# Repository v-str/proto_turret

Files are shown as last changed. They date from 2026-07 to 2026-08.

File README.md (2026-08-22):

<div align="center">

# proto_turret

**Панорамно-наклонная турель на STM32F446RE под управлением ROS 2 (micro-ROS)**







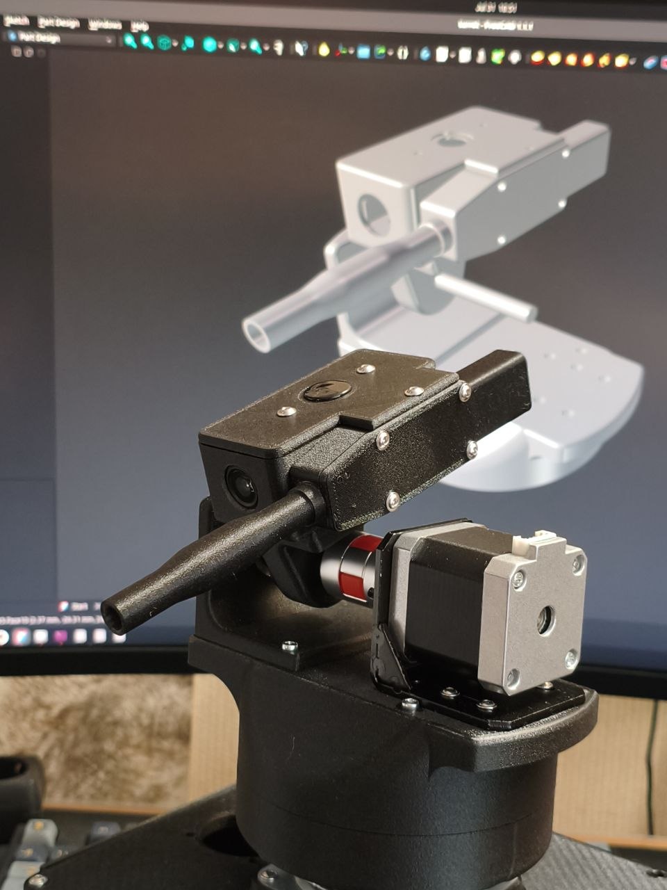
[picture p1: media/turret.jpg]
Собранная турель proto_turret


</div>

---

## О проекте

**proto_turret** — двухосевая турель (панорама + наклон), которая управляется через ROS 2.
Прошивка STM32 построена на **FreeRTOS** и **micro-ROS**: плата становится полноценной нодой
ROS-сети, обмениваясь сообщениями с ПК через UART (DMA + IDLE-прерывание).

На хосте работает Qt6-приложение: получает видео с USB-камеры, рисует прицельный интерфейс,
а движение мыши превращает в команды положения для турели.

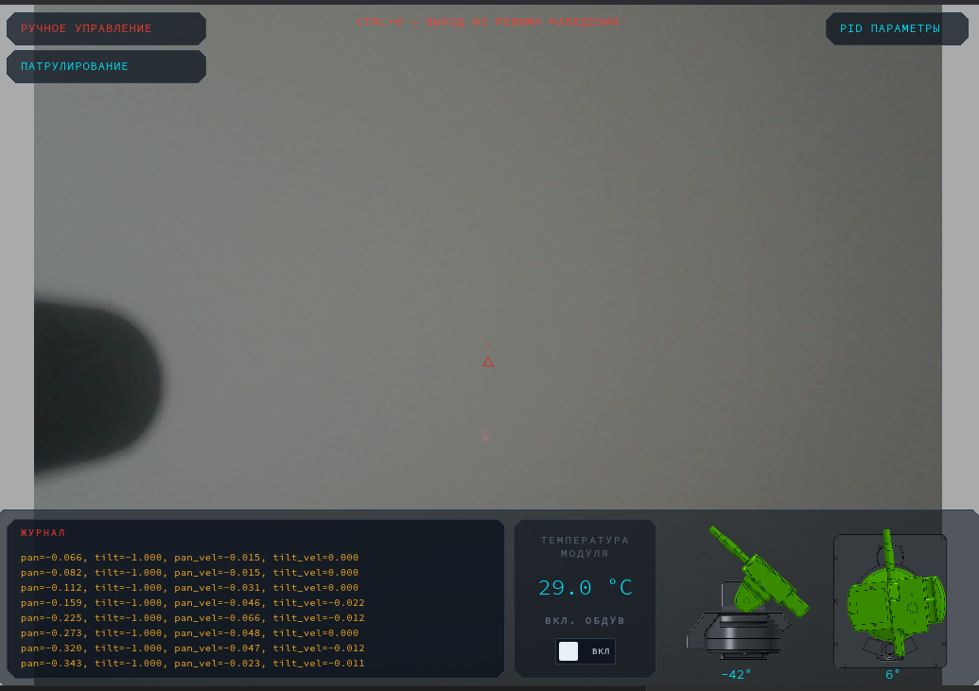
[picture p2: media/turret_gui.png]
Qt6 GUI турели


## Возможности

- 2 оси (pan/tilt) на шаговых двигателях NEMA17 с драйверами TMC2209 (STEP/DIR)
- Замкнутая обратная связь: магнитные энкодеры **AS5600** по каждой оси (I2C)
- **Автокалибровка** обеих осей по концевикам одним вызовом ROS-сервиса
- **PID-регуляция** скорости с раздельными коэффициентами на каждую ось,
  настройка всех 14 параметров **в рантайме** через ROS-сервис
- Телеметрия: углы осей, состояние 4 концевиков, температура (**LM75**, I2C)
- Управление охлаждающим вентилятором прямо из команды движения
- Аппаратная защита: моторы отключены до подключения агента; стоп при отсутствии
  команд дольше 100 мс; таймаут калибровки по числу шагов
- Корпус напечатан на 3D-принтере (FreeCAD-модели и STL приложены)

**Как это работает при загрузке:**

1. Плата стартует с **выключенными** драйверами моторов (EN = HIGH).
2. Главный цикл пингует micro-ros-agent каждые 2 секунды.
3. Когда агент найден → создаётся нода `proto_turret_node`: подписчик команд, публикация
   телеметрии, сервисы калибровки и PID-параметров.
4. Второй поток (`Ros2TaskExecutor`) разбирает очередь команд и управляет турелью.
   Если команды перестали приходить более чем на 100 мс — моторы останавливаются.
5. По запросу сервиса `/turret_calibrate` турель едет до концевиков каждой оси,
   считает шаги полного хода и принимает середину за ноль градусов.

## Железо

| Компонент | Модель | Подключение |
|---|---|---|
| Плата | NUCLEO-F446RE (STM32F446RE, Cortex-M4 @ 180 МГц) | USB (ST-Link + VCP) |
| Моторы | 2× NEMA17 | STEP/DIR (TIM10/TIM11) |
| Драйверы | 2× TMC2209 | STEP/DIR + EN (GPIO) |
| Энкодеры | 2× AS5600 | I2C1 (400 кГц) / I2C2 (100 кГц) |
| Датчик температуры | LM75 | I2C3 (100 кГц) |
| Концевики | 4 шт (лево/право, перед/зад) | GPIO |
| Вентилятор | — | GPIO |
| Камера | любая USB | хост-ПК |
| Канал связи | UART2, 115200 бод, DMA circular 2048 Б + IDLE | micro-ROS |

## Прошивка

Исходники — в [`Core/Src`](Core/Src). Проект генерируется CubeMX ([`proto_turret.ioc`](proto_turret.ioc)),
сборка через Makefile (arm-none-eabi-gcc, hard-float).

| Модуль | Назначение |
|---|---|
| [`transport.c`](Core/Src/transport.c) | весь micro-ROS: инициализация ноды, подписчик, публикаторы, сервисы, ping агента |
| [`turret_tasks.c`](Core/Src/turret_tasks.c) | потоки FreeRTOS, очередь команд, автокалибровка осей |
| [`motor_control.c`](Core/Src/motor_control.c) | STEP/DIR управление TMC2209, PID, движение до концевика |
| [`pid_struct.c`](Core/Src/pid_struct.c) | шаг PID-регулятора (сглаживание скорости, лимит разгона) |
| [`sensors.c`](Core/Src/sensors.c) | чтение AS5600 и LM75, медианный фильтр, восстановление зависшей I2C-шины |
| [`constants.h`](Core/Inc/constants.h) | все настраиваемые константы прошивки в одном файле |

Все настройки ROS-имён, PID, таймингов — в [`constants.h`](Core/Inc/constants.h).

### Потоки FreeRTOS

| Поток | Что делает |
|---|---|
| `defaultTask` (`StartDefaultTask`) | пинг агента → init micro-ROS → цикл `spin_some` + публикация телеметрии |
| `ros2TaskExecutor` | ждёт команду из очереди (таймаут 100 мс), двигает моторы по PID, включает вентилятор |

## ROS-интерфейс

Нода: **`/proto_turret_node`**

Кастомные сообщения и сервисы живут в пакете
[`microros_component/extra_packages/proto_turret_interfaces`](microros_component/extra_packages/proto_turret_interfaces)
и подхватываются при сборке libmicroros.

### Топики

| Направление | Имя | Тип | Частота |
|---|---|---|---|
| подписка | `/proto_turret_cmd` | `proto_turret_interfaces/msg/TurretCommand` | по мере прихода |
| публикация | `/proto_turret_stm32_publisher` | `proto_turret_interfaces/msg/TurretStatus` | 4 Гц |
| публикация | `/proto_turret_as5600` | `std_msgs/msg/Int32MultiArray` | 10 Гц |

```text
# TurretCommand.msg — команда от GUI
float32 pan_pos       # цель по панораме
float32 tilt_pos      # цель по наклону
float32 pan_vel
float32 tilt_vel
bool fan_enable       # включить вентилятор
```

```text
# TurretStatus.msg — телеметрия платы
uint8 switch_mask     # биты 0..3: левый, правый, передний, задний концевики
float32 temperature   # LM75, °C
bool fan_enable
int32 pan_angle       # текущий угол панорамы
int32 tilt_angle      # текущий угол наклона
```

`Int32MultiArray` на `/proto_turret_as5600` — сырые отсчёты энкодеров `[M1, M2, ошибки]`
(0..4095, `-1` = нет ответа) для отладки.

### Сервисы

| Имя | Тип | Назначение |
|---|---|---|
| `/turret_calibrate` | `proto_turret_interfaces/srv/TurretCalibrate` | автокалибровка обеих осей по концевикам, ответ `success` |
| `/turret_pid_params` | `proto_turret_interfaces/srv/PidParams` | применение 14 PID-коэффициентов (kp/ki/kd/smooth/rate/corr_max/speed_max × 2 оси) без перепрошивки |

## Сборка и запуск

### Что понадобится

- **Docker** — для сборки `libmicroros.a`
- **arm-none-eabi-gcc** + make — для сборки прошивки (либо всё то же в Docker)
- **OpenOCD** + ST-Link — для прошивки
- **ROS 2** на хосте и собранный из исходников `micro_ros_agent`
- ROS 2: библиотека micro-ROS собрана под Humble, хост-стек — Lyrical

### Сборка прошивки

```bash
git clone https://github.com/v-str/proto_turret.git
cd proto_turret

# 1. libmicroros.a в Docker (образ microros/micro_ros_static_library_builder:humble-cached;
#    внутри контейнера также собираются интерфейсы из microros_component/extra_packages)
./build_lib_docker.sh

# 2. Прошивка
make -j$(nproc)            # результат: build/proto_turret.hex/.bin/.elf
# либо полностью в Docker: ./build_fw_docker.sh

# 3. Прошивка платы через ST-Link (program + verify + reset)
./flash_stm32.sh
```

### Запуск на хосте

```bash
# 4. micro-ros-agent (нативно, не в Docker — так надёжнее для DDS)
./agent_start_native.sh

# 5. В другом терминале
source /opt/ros/lyrical/setup.bash
ros2 node list                          # → /proto_turret_node
ros2 topic echo /proto_turret_stm32_publisher

# 6. Откалибровать обе оси (поедет до концевиков и вернётся в центр)
ros2 service call /turret_calibrate proto_turret_interfaces/srv/TurretCalibrate "{}"

# 7. Подёрнуть турель вручную
ros2 topic pub --once /proto_turret_cmd proto_turret_interfaces/msg/TurretCommand \
  "{pan_pos: 0.3, tilt_pos: 0.0, pan_vel: 0.0, tilt_vel: 0.0, fan_enable: false}"
```

## Механика

Корпус и узлы турели спроектированы в FreeCAD — исходники в [`freecad/`](freecad),
готовые к печати STL (43 детали) — в [`freecad/stl/`](freecad/stl):

- `turret.FCStd` — основной корпус: колпак, дверца, ствол, капоты моторов, Y-сочленение
- `bottom_rails.FCStd` — нижние направляющие и углы
- `as5600_plate.FCStd` — крепление энкодеров AS5600
- `raspr_plata_holder.FCStd` — держатель распределительной платы

## Структура репозитория

```text
proto_turret/
├── Core/                        # исходники прошивки (main, задачи, транспорт, моторы, датчики)
├── Drivers/, Middlewares/       # HAL STM32 + CMSIS, FreeRTOS
├── micro_ros_stm32cubemx_utils/ # интеграция micro-ROS в CubeMX-проект (libmicroros.a)
├── microros_component/
│   └── extra_packages/
│       └── proto_turret_interfaces/   # кастомные msg/srv ROS
├── freecad/                     # 3D-модели (FreeCAD) и STL для печати
├── media/                       # фото и скриншоты
├── proto_turret.ioc             # проект CubeMX
├── Makefile                     # сборка прошивки (arm-none-eabi-gcc)
├── build_lib_docker.sh          # сборка libmicroros.a в Docker
├── build_fw_docker.sh           # сборка прошивки в Docker
├── flash_stm32.sh               # прошивка через OpenOCD + ST-Link
└── agent_start_native.sh        # запуск micro-ros-agent на хосте
```

## Статус

- [x] Транспорт micro-ROS: UART2 DMA + IDLE, автоматическое переподключение к агенту
- [x] Управление двумя осями STEP/DIR
- [x] Автокалибровка по концевикам
- [x] Энкодеры AS5600 с фильтрацией скачков
- [x] PID-регуляция + runtime-настройка через ROS-сервис
- [x] Телеметрия: концевики, температура LM75, углы осей
- [x] Qt6 GUI на хосте: видео, прицеливание мышью, PID-панель

---

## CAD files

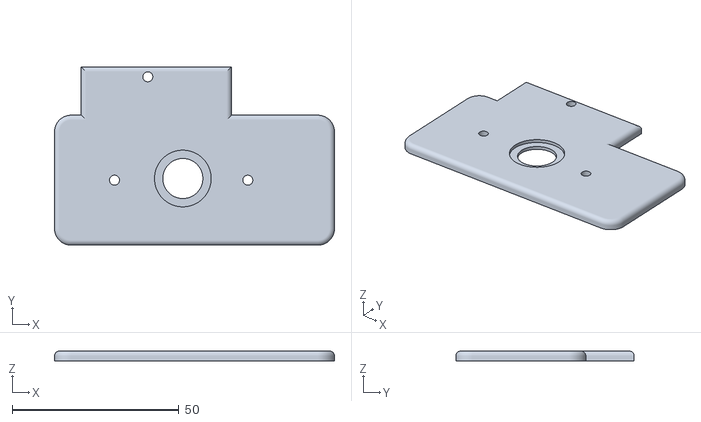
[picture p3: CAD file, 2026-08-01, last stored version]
freecad/stl/turret-turret_main_cap.stl
84.0 x 53.5 x 3.00

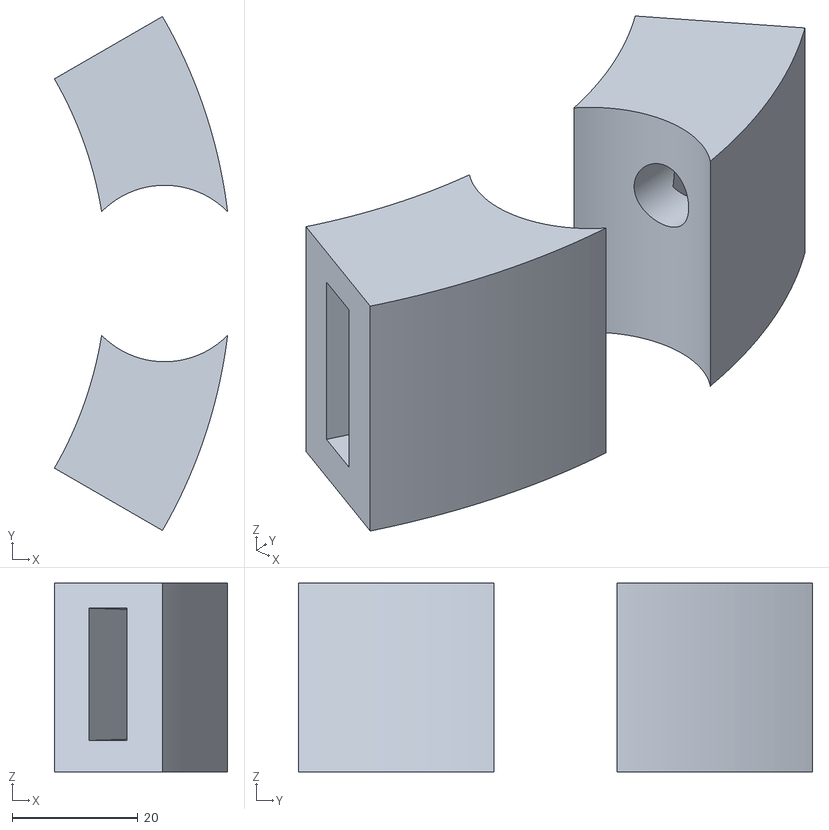
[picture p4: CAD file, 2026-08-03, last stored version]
freecad/stl/turret-head_konceviki_arms.stl
27.5 x 81.6 x 30.0

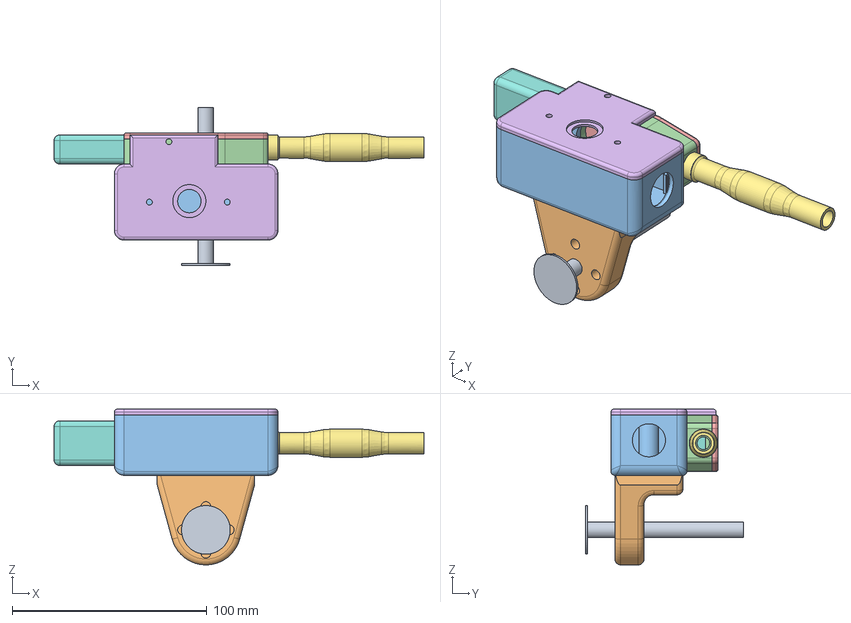
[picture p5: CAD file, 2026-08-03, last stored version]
freecad/turret.FCStd
190.0 x 81.0 x 80.0 mm
temp1
val_joint_y
turret_camera
turret_gun_base
turret_gun_base_cap
turret_main_cap
the_gun
the_gun_back

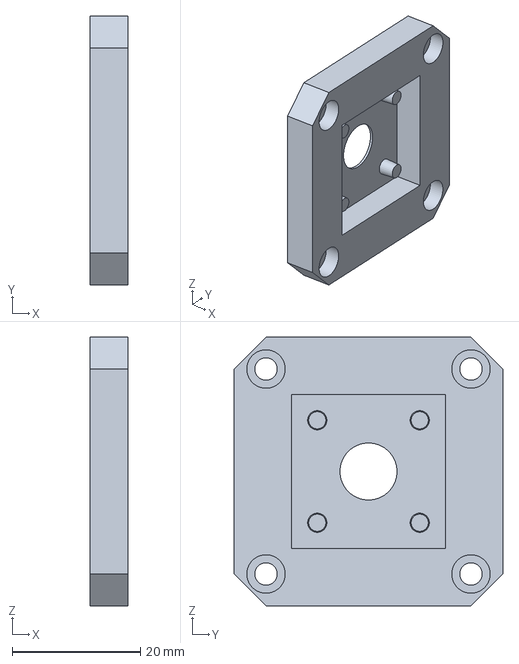
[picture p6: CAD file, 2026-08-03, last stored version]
freecad/as5600_plate.FCStd
6.00 x 42.0 x 42.0 mm

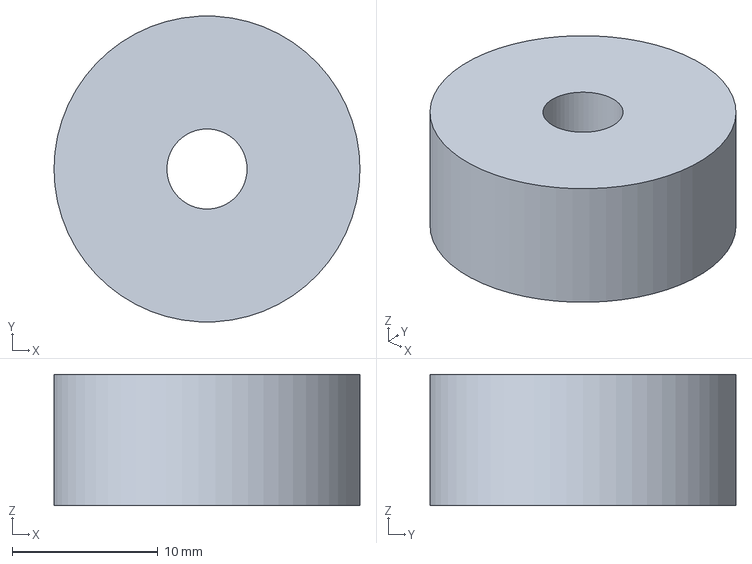
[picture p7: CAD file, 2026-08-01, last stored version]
freecad/motor_pan_gasket.FCStd
21.0 x 21.0 x 9.00 mm

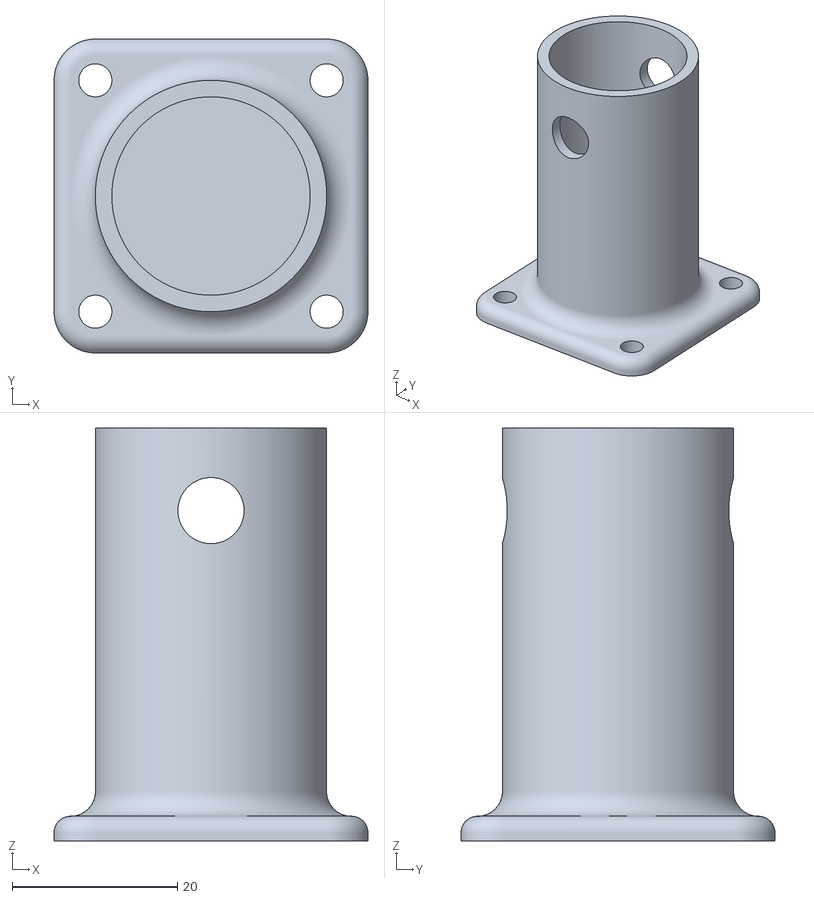
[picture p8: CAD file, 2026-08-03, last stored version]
freecad/stl/turret-head_konceviki_plate.stl
38.0 x 38.0 x 50.0

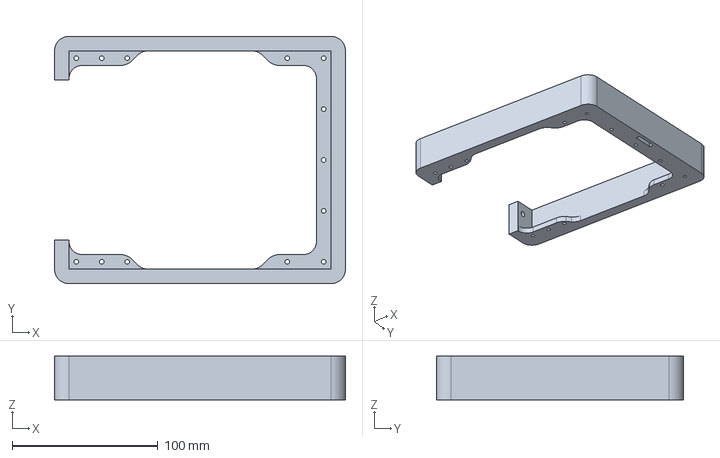
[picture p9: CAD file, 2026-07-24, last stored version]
freecad/box.FCStd
200.0 x 170.0 x 30.0 mm

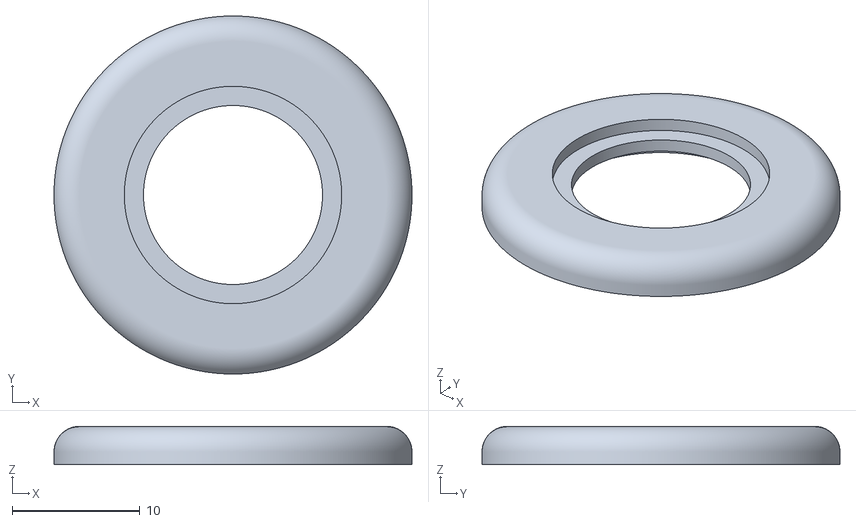
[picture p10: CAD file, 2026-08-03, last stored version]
freecad/stl/turret-head_konceviki_cap.stl
28.0 x 28.0 x 3.00

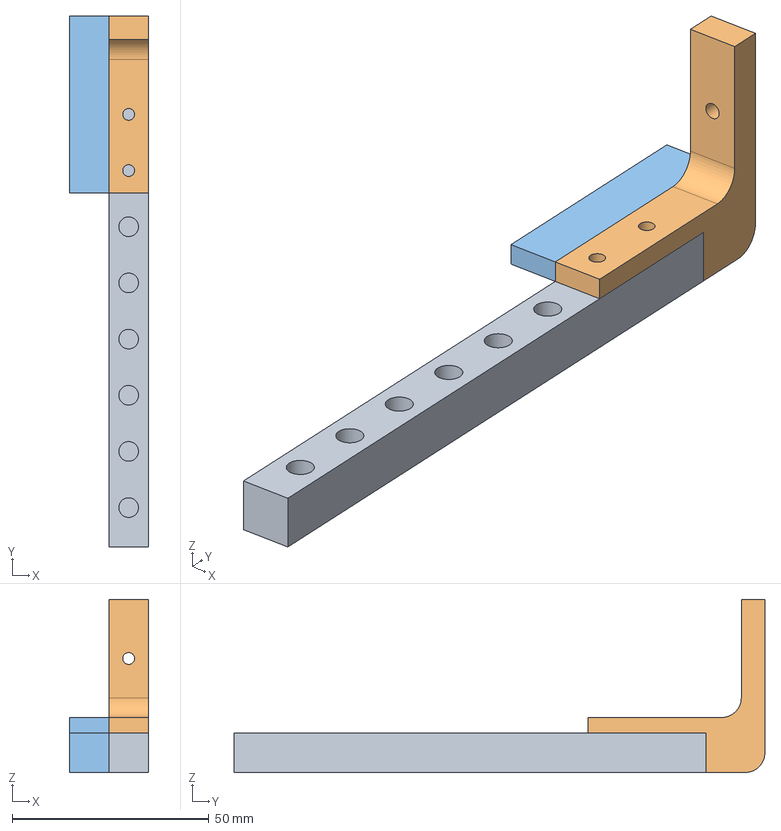
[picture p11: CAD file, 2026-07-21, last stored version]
freecad/bottom_rails.FCStd
20.0 x 135.0 x 44.0 mm
bottom_rails
corners
corner_side

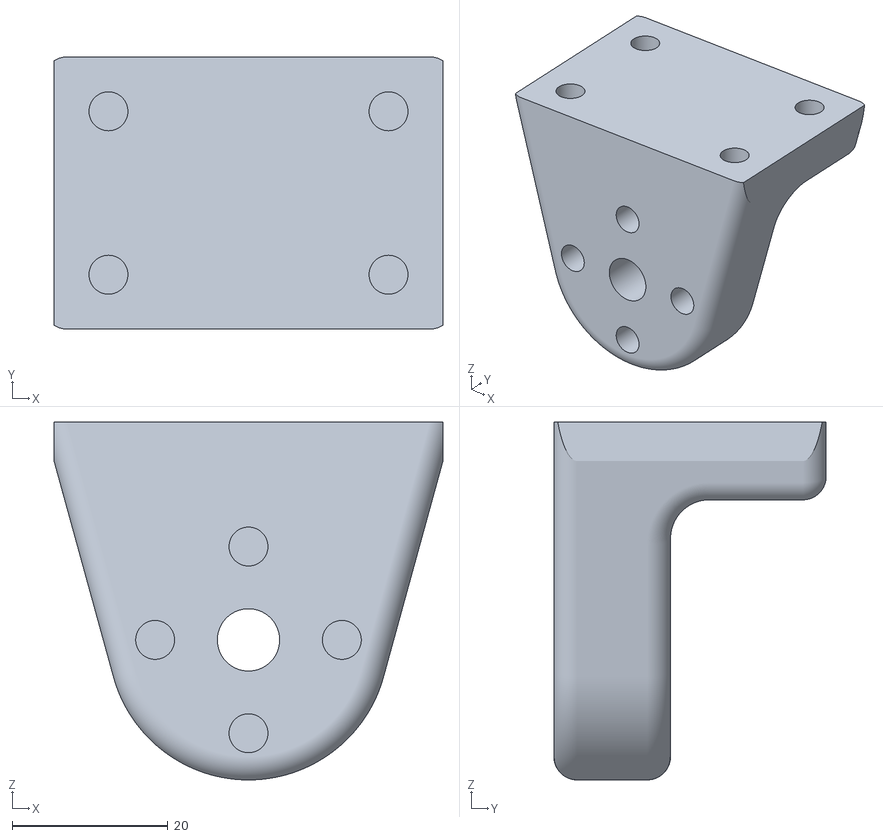
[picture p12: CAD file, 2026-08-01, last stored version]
freecad/stl/turret-val_joint_y.stl
50.0 x 35.0 x 46.0

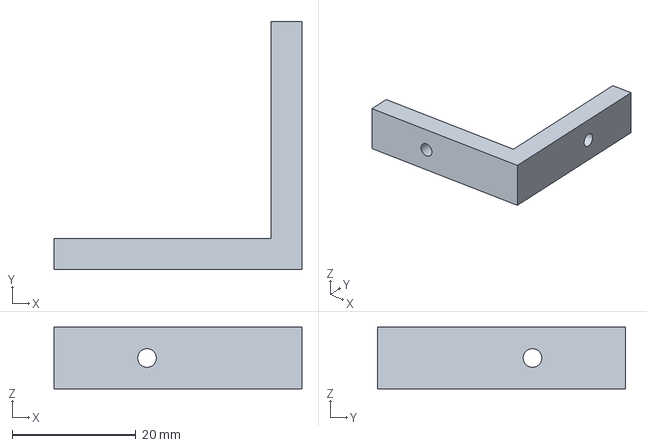
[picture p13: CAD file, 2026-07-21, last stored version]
freecad/corners_small_plate.FCStd
40.0 x 40.0 x 10.0 mm

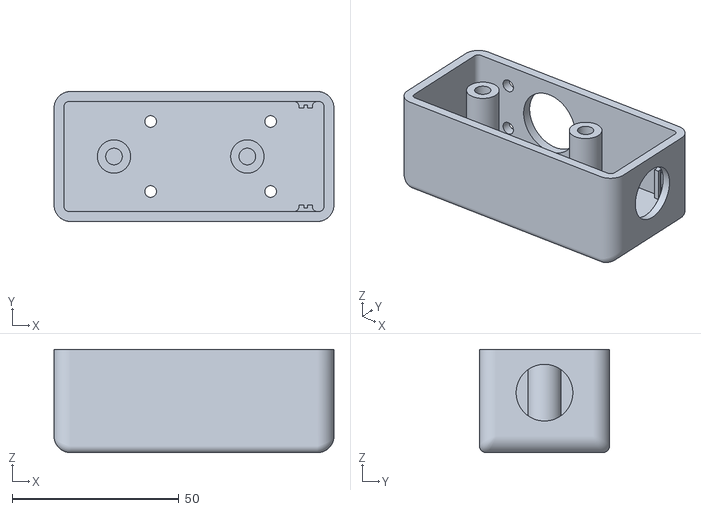
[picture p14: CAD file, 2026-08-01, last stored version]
freecad/stl/turret-turret_camera.stl
84.0 x 39.0 x 31.0

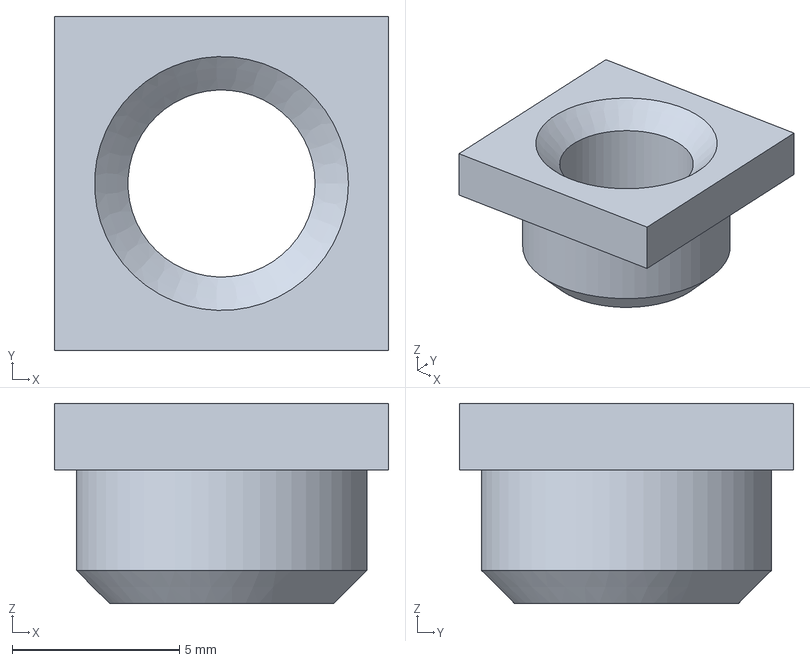
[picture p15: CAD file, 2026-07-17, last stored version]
freecad/magnet_template_helper.FCStd
10.0 x 10.0 x 6.00 mm

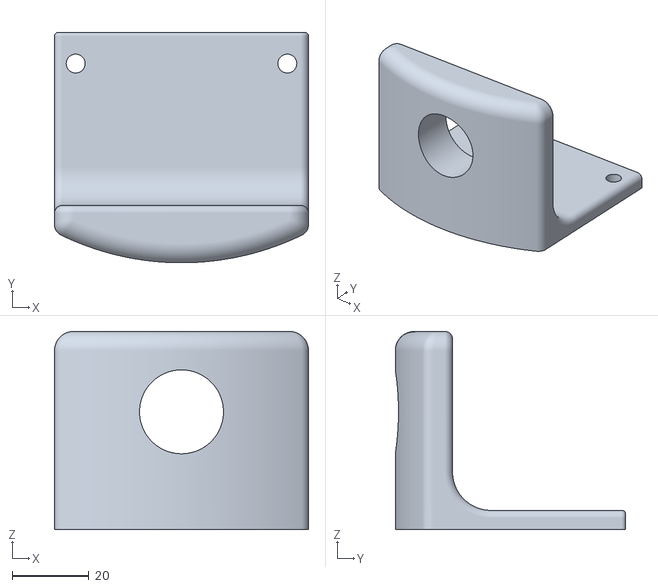
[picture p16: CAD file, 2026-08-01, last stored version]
freecad/stl/turret-motor_y_joint.stl
66.0 x 59.9 x 51.5

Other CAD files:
freecad/stl/as5600_plate-as5600_plate.stl
freecad/stl/motor_pan_gasket-motor_gasket.stl
freecad/stl/turret-the_gun.stl
freecad/stl/turret-gun_konceviki.stl
freecad/stl/bottom_rails-Body.stl
freecad/stl/bottom_rails-corner_side.stl
freecad/stl/box-Inter_stick.stl
freecad/stl/box-bottom_plate.stl
freecad/stl/box-great_wall.stl
freecad/stl/box-supply_unit_holder.stl
freecad/stl/box-wall_1.stl
freecad/stl/box-wall_2.stl
freecad/stl/box-wall_3.stl
freecad/stl/corners_small_plate-Body.stl
freecad/stl/magnet_template_helper-Body.stl
freecad/stl/rails-corners.stl
freecad/stl/turret-box_cap_gasket.stl
freecad/stl/turret-cap.stl
freecad/stl/turret-door.stl
freecad/stl/turret-head_motor_plate.stl
freecad/stl/turret-motor_hood_box.stl
freecad/stl/turret-motor_hood_roof.stl
freecad/stl/turret-motor_tilt_plate.stl
freecad/stl/turret-plate_joints.stl
freecad/stl/turret-the_gun_back.stl
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

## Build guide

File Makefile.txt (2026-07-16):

##########################################################################################################################
# File automatically-generated by tool: [projectgenerator] version: [4.10.0-B28] date: [Thu Jul 16 12:32:29 MSK 2026] 
##########################################################################################################################

# ------------------------------------------------
# Generic Makefile (based on gcc)
#
# ChangeLog :
#	2017-02-10 - Several enhancements + project update mode
#   2015-07-22 - first version
# ------------------------------------------------

######################################
# target
######################################
TARGET = proto_turret

######################################
# building variables
######################################
# debug build?
DEBUG = 1
# optimization
OPT = -Og

#######################################
# paths
#######################################
# Build path
BUILD_DIR = build

######################################
# source
######################################
# C sources
C_SOURCES =  \
Core/Src/main.c \
Core/Src/freertos.c \
Core/Src/stm32f4xx_it.c \
Core/Src/stm32f4xx_hal_msp.c \
Core/Src/stm32f4xx_hal_timebase_tim.c \
Drivers/BSP/STM32F4xx-Nucleo/stm32f4xx_nucleo.c \
Drivers/STM32F4xx_HAL_Driver/Src/stm32f4xx_hal_tim.c \
Drivers/STM32F4xx_HAL_Driver/Src/stm32f4xx_hal_tim_ex.c \
Drivers/STM32F4xx_HAL_Driver/Src/stm32f4xx_hal_rcc.c \
Drivers/STM32F4xx_HAL_Driver/Src/stm32f4xx_hal_rcc_ex.c \
Drivers/STM32F4xx_HAL_Driver/Src/stm32f4xx_hal_flash.c \
Drivers/STM32F4xx_HAL_Driver/Src/stm32f4xx_hal_flash_ex.c \
Drivers/STM32F4xx_HAL_Driver/Src/stm32f4xx_hal_flash_ramfunc.c \
Drivers/STM32F4xx_HAL_Driver/Src/stm32f4xx_hal_gpio.c \
Drivers/STM32F4xx_HAL_Driver/Src/stm32f4xx_hal_dma_ex.c \
Drivers/STM32F4xx_HAL_Driver/Src/stm32f4xx_hal_dma.c \
Drivers/STM32F4xx_HAL_Driver/Src/stm32f4xx_hal_pwr.c \
Drivers/STM32F4xx_HAL_Driver/Src/stm32f4xx_hal_pwr_ex.c \
Drivers/STM32F4xx_HAL_Driver/Src/stm32f4xx_hal_cortex.c \
Drivers/STM32F4xx_HAL_Driver/Src/stm32f4xx_hal.c \
Drivers/STM32F4xx_HAL_Driver/Src/stm32f4xx_hal_exti.c \
Drivers/STM32F4xx_HAL_Driver/Src/stm32f4xx_hal_uart.c \
Core/Src/system_stm32f4xx.c \
Middlewares/Third_Party/FreeRTOS/Source/croutine.c \
Middlewares/Third_Party/FreeRTOS/Source/event_groups.c \
Middlewares/Third_Party/FreeRTOS/Source/list.c \
Middlewares/Third_Party/FreeRTOS/Source/queue.c \
Middlewares/Third_Party/FreeRTOS/Source/stream_buffer.c \
Middlewares/Third_Party/FreeRTOS/Source/tasks.c \
Middlewares/Third_Party/FreeRTOS/Source/timers.c \
Middlewares/Third_Party/FreeRTOS/Source/CMSIS_RTOS_V2/cmsis_os2.c \
Middlewares/Third_Party/FreeRTOS/Source/portable/MemMang/heap_4.c \
Middlewares/Third_Party/FreeRTOS/Source/portable/GCC/ARM_CM4F/port.c \
Core/Src/sysmem.c \
Core/Src/syscalls.c \
micro_ros_stm32cubemx_utils/extra_sources/microros_transports/dma_transport.c \
micro_ros_stm32cubemx_utils/extra_sources/microros_allocators.c \
micro_ros_stm32cubemx_utils/extra_sources/custom_memory_manager.c \
micro_ros_stm32cubemx_utils/extra_sources/microros_time.c

# ASM sources
ASM_SOURCES =  \
startup_stm32f446xx.s

# ASMM sources
ASMM_SOURCES = 

#######################################
# binaries
#######################################
PREFIX = arm-none-eabi-
# The gcc compiler bin path can be either defined in make command via GCC_PATH variable (> make GCC_PATH=xxx)
# either it can be added to the PATH environment variable.
ifdef GCC_PATH
CC = $(GCC_PATH)/$(PREFIX)gcc
AS = $(GCC_PATH)/$(PREFIX)gcc -x assembler-with-cpp
CP = $(GCC_PATH)/$(PREFIX)objcopy
SZ = $(GCC_PATH)/$(PREFIX)size
else
CC = $(PREFIX)gcc
AS = $(PREFIX)gcc -x assembler-with-cpp
CP = $(PREFIX)objcopy
SZ = $(PREFIX)size
endif
HEX = $(CP) -O ihex
BIN = $(CP) -O binary -S
 
#######################################
# CFLAGS
#######################################
# cpu
CPU = -mcpu=cortex-m4

# fpu
FPU = -mfpu=fpv4-sp-d16

# float-abi
FLOAT-ABI = -mfloat-abi=hard

# mcu
MCU = $(CPU) -mthumb $(FPU) $(FLOAT-ABI)

# macros for gcc
# AS defines
AS_DEFS = 

# C defines
C_DEFS =  \
-DUSE_NUCLEO_64 \
-DUSE_HAL_DRIVER \
-DSTM32F446xx

# AS includes
AS_INCLUDES =  \
-ICore/Inc \
-IDrivers/STM32F4xx_HAL_Driver/Inc \
-IDrivers/STM32F4xx_HAL_Driver/Inc/Legacy \
-IMiddlewares/Third_Party/FreeRTOS/Source/include \
-IMiddlewares/Third_Party/FreeRTOS/Source/CMSIS_RTOS_V2 \
-IMiddlewares/Third_Party/FreeRTOS/Source/portable/GCC/ARM_CM4F \
-IDrivers/BSP/STM32F4xx-Nucleo \
-IDrivers/CMSIS/Device/ST/STM32F4xx/Include \
-IDrivers/CMSIS/Include

# C includes
C_INCLUDES =  \
-ICore/Inc \
-IDrivers/STM32F4xx_HAL_Driver/Inc \
-IDrivers/STM32F4xx_HAL_Driver/Inc/Legacy \
-IMiddlewares/Third_Party/FreeRTOS/Source/include \
-IMiddlewares/Third_Party/FreeRTOS/Source/CMSIS_RTOS_V2 \
-IMiddlewares/Third_Party/FreeRTOS/Source/portable/GCC/ARM_CM4F \
-IDrivers/BSP/STM32F4xx-Nucleo \
-IDrivers/CMSIS/Device/ST/STM32F4xx/Include \
-IDrivers/CMSIS/Include \
-Imicro_ros_stm32cubemx_utils/microros_static_library/libmicroros/microros_include

# compile gcc flags
ASFLAGS = $(MCU) $(AS_DEFS) $(AS_INCLUDES) $(OPT) -Wall -fdata-sections -ffunction-sections

CFLAGS += $(MCU) $(C_DEFS) $(C_INCLUDES) $(OPT) -Wall -fdata-sections -ffunction-sections

ifeq ($(DEBUG), 1)
CFLAGS += -g -gdwarf-2
endif

# Generate dependency information
CFLAGS += -MMD -MP -MF"$(@:%.o=%.d)"

#######################################
# LDFLAGS
#######################################
# link script
LDSCRIPT = STM32F446xx_FLASH.ld

# libraries
# LIBS = -lc -lm -lnosys
LIBS = -lc -lm -lnosys -Lmicro_ros_stm32cubemx_utils/microros_static_library/libmicroros -lmicroros

LIBDIR = 
LDFLAGS = $(MCU) -specs=nano.specs -T$(LDSCRIPT) $(LIBDIR) $(LIBS) -Wl,-Map=$(BUILD_DIR)/$(TARGET).map,--cref -Wl,--gc-sections

# default action: build all
all: $(BUILD_DIR)/$(TARGET).elf $(BUILD_DIR)/$(TARGET).hex $(BUILD_DIR)/$(TARGET).bin

# print compiler flags (used by micro-ROS library build)
print_cflags:
	@echo $(MCU) $(OPT)

#######################################
# build the application
#######################################
# list of objects
OBJECTS = $(addprefix $(BUILD_DIR)/,$(notdir $(C_SOURCES:.c=.o)))
vpath %.c $(sort $(dir $(C_SOURCES)))
# list of ASM program objects
OBJECTS += $(addprefix $(BUILD_DIR)/,$(notdir $(ASM_SOURCES:.s=.o)))
vpath %.s $(sort $(dir $(ASM_SOURCES)))
OBJECTS += $(addprefix $(BUILD_DIR)/,$(notdir $(ASMM_SOURCES:.S=.o)))
vpath %.S $(sort $(dir $(ASMM_SOURCES)))

$(BUILD_DIR)/%.o: %.c Makefile | $(BUILD_DIR) 
	$(CC) -c $(CFLAGS) -Wa,-a,-ad,-alms=$(BUILD_DIR)/$(notdir $(<:.c=.lst)) $< -o $@

$(BUILD_DIR)/%.o: %.s Makefile | $(BUILD_DIR)
	$(AS) -c $(CFLAGS) $< -o $@
$(BUILD_DIR)/%.o: %.S Makefile | $(BUILD_DIR)
	$(AS) -c $(CFLAGS) $< -o $@

$(BUILD_DIR)/$(TARGET).elf: $(OBJECTS) Makefile
	$(CC) $(OBJECTS) $(LDFLAGS) -o $@
	$(SZ) $@

$(BUILD_DIR)/%.hex: $(BUILD_DIR)/%.elf | $(BUILD_DIR)
	$(HEX) $< $@
	
$(BUILD_DIR)/%.bin: $(BUILD_DIR)/%.elf | $(BUILD_DIR)
	$(BIN) $< $@	
	
$(BUILD_DIR):
	mkdir $@		

#######################################
# clean up
#######################################
clean:
	-rm -fR $(BUILD_DIR)
  
#######################################
# dependencies
#######################################
-include $(wildcard $(BUILD_DIR)/*.d)

# *** EOF ***

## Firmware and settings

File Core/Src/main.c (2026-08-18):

// ============================================================================
// main.c — только запуск турели.
// Вся инициализация вынесена в turret_init.c, потоки и транспорт — в
// turret_tasks.c, чтение датчиков — в sensors.c, моторы — в motor_control.c.
// Здесь остаётся: точка входа, тактирование, системные коллбэки и
// Error_Handler.
// ============================================================================

#include "main.h"

#include "cmsis_os.h"     // osKernelStart — запуск планировщика FreeRTOS
#include "constants.h"  // RCC_PLL*, BUTTON_RELEASED/PRESSED
#include "turret_init.h"  // turret_init — вся инициализация турели

// Состояние кнопки: обновляет прерывание EXTI (HAL_GPIO_EXTI_Callback ниже)
__IO uint32_t BspButtonState = BUTTON_RELEASED;

void SystemClock_Config(void);

int main(void) {
  HAL_Init();            // сброс периферии, FLASH, SysTick
  SystemClock_Config();  // тактирование: HSI + PLL → 84 МГц
  turret_init();         // периферия, BSP, RTOS и потоки (turret_init.c)
  osKernelStart();  // запуск планировщика FreeRTOS — дальше управляют потоки
  while (1) {
  }  // сюда управление не возвращается
}

// ----------------------------------------------------------------------------
// Тактирование системы.
// Источник: HSI 16 МГц, умножение через PLL:
//   PLLM = 16  → 16/16 = 1 МГц (на вход VCO)
//   PLLN = 336 → VCO = 336 МГц
//   PLLP = 4   → SYSCLK = 336/4 = 84 МГц
// Делители шин: HCLK = 84 МГц (/1), APB1 = 42 МГц (/2), APB2 = 84 МГц (/1).
// ----------------------------------------------------------------------------
void SystemClock_Config(void) {
  RCC_OscInitTypeDef RCC_OscInitStruct = {0};
  RCC_ClkInitTypeDef RCC_ClkInitStruct = {0};

  // Регулятор напряжения ядра (пониженное питание — VOS3)
  __HAL_RCC_PWR_CLK_ENABLE();
  __HAL_PWR_VOLTAGESCALING_CONFIG(PWR_REGULATOR_VOLTAGE_SCALE3);

  // Запускаем HSI 16 МГц и настраиваем PLL
  RCC_OscInitStruct.OscillatorType = RCC_OSCILLATORTYPE_HSI;
  RCC_OscInitStruct.HSIState = RCC_HSI_ON;
  RCC_OscInitStruct.HSICalibrationValue = RCC_HSICALIBRATION_DEFAULT;
  RCC_OscInitStruct.PLL.PLLState = RCC_PLL_ON;
  RCC_OscInitStruct.PLL.PLLSource = RCC_PLLSOURCE_HSI;
  RCC_OscInitStruct.PLL.PLLM = RCC_PLLM;
  RCC_OscInitStruct.PLL.PLLN = RCC_PLLN;
  RCC_OscInitStruct.PLL.PLLP = RCC_PLLP_DIV4;
  RCC_OscInitStruct.PLL.PLLQ = RCC_PLLQ;
  RCC_OscInitStruct.PLL.PLLR = RCC_PLLR;
  if (HAL_RCC_OscConfig(&RCC_OscInitStruct) != HAL_OK) {
    Error_Handler();
  }

  // Системная шина от PLL + делители AHB / APB1 / APB2
  RCC_ClkInitStruct.ClockType = RCC_CLOCKTYPE_HCLK | RCC_CLOCKTYPE_SYSCLK |
                                RCC_CLOCKTYPE_PCLK1 | RCC_CLOCKTYPE_PCLK2;
  RCC_ClkInitStruct.SYSCLKSource = RCC_SYSCLKSOURCE_PLLCLK;
  RCC_ClkInitStruct.AHBCLKDivider = RCC_SYSCLK_DIV1;
  RCC_ClkInitStruct.APB1CLKDivider = RCC_HCLK_DIV2;
  RCC_ClkInitStruct.APB2CLKDivider = RCC_HCLK_DIV1;

  // FLASH_LATENCY_2 — 2 цикла ожидания для Flash при тактовой 84 МГц
  if (HAL_RCC_ClockConfig(&RCC_ClkInitStruct, FLASH_LATENCY_2) != HAL_OK) {
    Error_Handler();
  }
}

// ----------------------------------------------------------------------------
// Системные коллбэки HAL.
// ----------------------------------------------------------------------------

// // Тайм-база: вызывается из прерывания таймера TIM1 и тикает счётчик
// // миллисекунд HAL_GetTick(). Без этого HAL_GetTick не работает.
// void HAL_TIM_PeriodElapsedCallback(TIM_HandleTypeDef* htim) {
//   if (htim->Instance == TIM1) {
//     HAL_IncTick();
//   }
// }

// Прерывание EXTI: пользовательская кнопка нажата → фиксируем состояние.
void HAL_GPIO_EXTI_Callback(uint16_t GPIO_Pin) {
  if (GPIO_Pin == USER_BUTTON_PIN) {
    BspButtonState = BUTTON_PRESSED;
  }
}

// Вызывается HAL-ом при критической ошибке инициализации:
// отключаем прерывания и останавливаемся в бесконечном цикле.
void Error_Handler(void) {
  __disable_irq();
  while (1) {
  }
}

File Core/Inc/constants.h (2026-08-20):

#ifndef PROTO_TURRET_CONSTANTS_H
#define PROTO_TURRET_CONSTANTS_H

// Все настраиваемые константы прошивки собраны здесь, в одном файле.
// Используется main.c, transport.c, sensors.c, motor_control.c,
// turret_tasks.c и turret_init.c. Железная разводка пинов (main.h, генерируется
// CubeMX) сюда НЕ переносится.

#include "main.h"  // GPIO_PIN_RESET/SET, GPIO_TypeDef для пинов I2C ниже

// ----------------------------------------------------------------------------
// ROS: имена ноды, топиков и сервиса
// ----------------------------------------------------------------------------
#define PID_NODE_NAME "proto_turret_node"
#define PID_TOPIC_CMD "/proto_turret_cmd"
#define PID_TOPIC_STATUS "/proto_turret_stm32_publisher"
#define PID_TOPIC_AS5600 \
  "/proto_turret_as5600"  // сырой угол AS5600 (0..4095, -1 = нет ответа)
#define PID_SERVICE_CALIBRATE \
  "/turret_calibrate"  // ROS-сервис калибровки турели
#define PID_SERVICE_PID_PARAMS \
  "/turret_pid_params"  // ROS-сервис применения PID-параметра
#define PID_QOS_DEPTH 10

// ----------------------------------------------------------------------------
// Энкодеры AS5600 (12 бит: 0..4095 на полный оборот)
// ----------------------------------------------------------------------------
#define ENC_COUNTS_PER_TURN 4096  // счётчиков на полный оборот
#define ENC_HALF_RANGE \
  (ENC_COUNTS_PER_TURN / 2)     // пол-оборота (граница обёртки)
#define ENC_INVALID (-1)        // «энкодер ещё не читался»
#define ENC_SAMPLE_MS 50        // опрос энкодеров (20 Гц)
#define ENC_DEADBAND 4          // шум шины: дельту меньше не накапливаем
#define ENC_REANCHOR 1024       // сбой/пропуск: дельту больше не доверяем
#define ENC_JUMP_MAX 1000       // скачок-фильтр: больше = мусор
#define AS5600_MSG_ELEMENTS 3   // элементов Int32MultiArray: [M1, M2, ошибки]
#define AS5600_MEDIAN_READS 3   // чтений подряд для медианы
#define AS5600_READ_ATTEMPTS 5  // попыток чтения угла (с рекавери шины)
#define AS5600_REG_WIDTH 2      // байт угла в регистре AS5600
#define AS5600_ANGLE_SHIFT 4    // старшие 12 бит из 16
#define AS5600_ERR_HAL_ERROR (-1)    // устройство не ответило (нет ACK)
#define AS5600_ERR_TIMEOUT (-2)      // шина зависла, обмен не завершился
#define AS5600_ERR_BUSY (-3)         // шина «залипла», не восстановилась
#define AS5600_ERR_OTHER (-4)        // другой код ошибки
#define AS5600_I2C_ADDR (0x36 << 1)  // 7-бит адрес AS5600 (сдвинут для I2C)
#define AS5600_REG_ANGLE 0x0C        // регистр угла: 2 байта (старший/младший)

// ----------------------------------------------------------------------------
// Датчик температуры LM75 (I2C3)
// ----------------------------------------------------------------------------
#define LM75_TEMP_ADDRESS (0x48 << 1)  // адрес LM75 (сдвинут на 1 бит для I2C)
#define LM75_REG_TEMP 0x00             // регистр температуры (чтение)
#define LM75_TEMP_BYTES 2              // байт на чтение
#define LM75_TEMP_SHIFT 7              // 9-бит температура в старших битах
#define LM75_TEMP_LSB 0.5f             // 0.5 °C на деление (9-бит)
#define LM75_TEMP_ABSENT (-1000.0f)    // датчик не подключен
#define LM75_TEMP_TIMEOUT (-1001.0f)   // обмен не успел за таймаут
#define LM75_TEMP_ERROR (-1002.0f)     // HAL_ERROR: датчик не ответил (NACK)

// ----------------------------------------------------------------------------
// Шины I2C: скорости, ретраи, таймауты, восстановление
// ----------------------------------------------------------------------------
#define I2C1_CLOCK_HZ 400000      // I2C1 — энкодер M1 (400 кГц)
#define I2C2_CLOCK_HZ 100000      // I2C2 — энкодер M2 (100 кГц)
#define I2C3_CLOCK_HZ 100000      // I2C3 — LM75 (100 кГц)
#define I2C_READY_TRIALS 3        // попыток проверки готовности датчика
#define I2C_READY_TIMEOUT_MS 100  // таймаут проверки готовности, мс
#define I2C_MEM_TIMEOUT_MS 50     // таймаут чтения регистра датчика, мс
#define I2C_RECOVERY_CLOCKS 9     // тактов SCL при bus-recovery
#define I2C_RECOVERY_DELAY_MS 1   // пауза между тактами SCL, мс
// Пины SCL/SDA каждой шины (для bus-recovery в sensors.c)
#define I2C1_SCL_PORT GPIOB
#define I2C1_SCL_PIN GPIO_PIN_6
#define I2C1_SDA_PORT GPIOB
#define I2C1_SDA_PIN GPIO_PIN_7
#define I2C2_SCL_PORT GPIOB
#define I2C2_SCL_PIN GPIO_PIN_10
#define I2C2_SDA_PORT GPIOC
#define I2C2_SDA_PIN GPIO_PIN_12
#define I2C3_SCL_PORT GPIOA
#define I2C3_SCL_PIN GPIO_PIN_8
#define I2C3_SDA_PORT GPIOC
#define I2C3_SDA_PIN GPIO_PIN_9

// ----------------------------------------------------------------------------
// Периоды публикации и пересчёты
// ----------------------------------------------------------------------------
#define STATUS_HEARTBEAT_MS 250  // heartbeat статуса (4 Гц)
#define AS5600_PUBLISH_MS 100    // публикация AS5600 (10 Гц)
#define TEMP_READ_MS 1000        // перечитывать LM75 раз в 1 с
#define DEG_PER_TURN 360.0f      // градусов на полный оборот
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

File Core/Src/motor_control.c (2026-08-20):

#include "motor_control.h"

#include <math.h>  // fabsf

#include "cmsis_os.h"  // osDelay
#include "pid_struct.h"
#include "sensors.h"

volatile uint8_t pan_dir = 0;
volatile uint8_t tilt_dir = 0;
volatile uint8_t pan_running = 0;
volatile uint8_t tilt_running = 0;

static PID_Struct pid_pan;
static PID_Struct pid_tilt;
static float target_pan_speed = 0.0f;
static float target_tilt_speed = 0.0f;
static uint8_t pid_active_pan = 0;
static uint8_t pid_active_tilt = 0;
static uint32_t last_pid_pan_ms = 0;
static uint32_t last_pid_tilt_ms = 0;
static float smooth_pan_speed = 0.0f;   // EMA измеренной скорости (норм. −1..1)
static float smooth_tilt_speed = 0.0f;
static float cur_pan_output = 0.0f;     // текущая команда (для rate-limit)
static float cur_tilt_output = 0.0f;

// --- Runtime PID-настройки (раздельные для каждой оси) ---
// Инициализируются из констант в motor_pid_init(); меняются в рантайме через
// motor_apply_pid_params() (для ROS2-сервиса параметров).
static float pan_kp = PAN_PID_KP_DEFAULT;
static float pan_ki = PAN_PID_KI_DEFAULT;
static float pan_kd = PAN_PID_KD_DEFAULT;
static float pan_smooth = PAN_PID_SPEED_SMOOTH;
static float pan_rate = PAN_PID_OUTPUT_RATE;
static float pan_corr_max = PAN_PID_CORRECTION_MAX_FRACTION;
static float pan_speed_max = PAN_PID_SPEED_MAX_DEG_PER_S;

static float tilt_kp = TILT_PID_KP_DEFAULT;
static float tilt_ki = TILT_PID_KI_DEFAULT;
static float tilt_kd = TILT_PID_KD_DEFAULT;
static float tilt_smooth = TILT_PID_SPEED_SMOOTH;
static float tilt_rate = TILT_PID_OUTPUT_RATE;
static float tilt_corr_max = TILT_PID_CORRECTION_MAX_FRACTION;
static float tilt_speed_max = TILT_PID_SPEED_MAX_DEG_PER_S;

// Обработка прерываний таймеров
void HAL_TIM_PeriodElapsedCallback(TIM_HandleTypeDef* htim) {
  if (htim->Instance == TIM1) {
    HAL_IncTick();
  }
  // TIM10 отвечает за панораму (горизонт)
  if (htim->Instance == TIM10) {
    if (is_motor_can_rotate_pan()) {
      HAL_GPIO_TogglePin(M1_STEP_GPIO_Port, M1_STEP_Pin);
    }
  }
  // TIM11 отвечает за тильт (вертикаль)
  if (htim->Instance == TIM11) {
    if (is_motor_can_rotate_tilt()) {
      HAL_GPIO_TogglePin(M2_STEP_GPIO_Port, M2_STEP_Pin);
    }
  }
}

// БЛОКИРУЮЩАЯ Ф-ЦИЯ (osDelay)
// Один шаг мотора: импульс на STEP (поднять-опустить) с задержкой delay мс.
static void motor_step_once(GPIO_TypeDef* step_port, uint16_t step_pin,
                            uint32_t delay) {
  HAL_GPIO_WritePin(step_port, step_pin, GPIO_PIN_SET);
  osDelay(delay);
  HAL_GPIO_WritePin(step_port, step_pin, GPIO_PIN_RESET);
  osDelay(delay);
}

// Шагать мотором в направлении dir, пока концевик (stop_port/stop_pin) не
// сработает (LOW). Возвращает число сделанных шагов; UINT32_MAX = концевик не
// сработал за CALIB_MAX_STEPS (ошибка).
static uint32_t motor_until_endstop(GPIO_TypeDef* dir_port, uint16_t dir_pin,
                                    GPIO_TypeDef* step_port, uint16_t step_pin,
                                    GPIO_TypeDef* stop_port, uint16_t stop_pin,
                                    uint8_t dir) {
  HAL_GPIO_WritePin(dir_port, dir_pin, dir);
  uint32_t steps = 0;
  while (!is_endstop_reached(stop_port, stop_pin)) {
    motor_step_once(step_port, step_pin, CALIB_STEP_DELAY_MS);
    if (++steps >= CALIB_MAX_STEPS) {
      return UINT32_MAX;
    }
  }
  return steps;
}

// Прошагать ровно steps шагов мотором в направлении dir.
static void motor_steps(GPIO_TypeDef* dir_port, uint16_t dir_pin,
                        GPIO_TypeDef* step_port, uint16_t step_pin,
                        uint32_t steps, uint8_t dir) {
  HAL_GPIO_WritePin(dir_port, dir_pin, dir);
  for (uint32_t i = 0; i < steps; i++) {
    motor_step_once(step_port, step_pin, CALIB_STEP_DELAY_MS);
  }
}

// Включить/выключить оба мотора (EN активен низким уровнем: 0 = включён).
void motor_enable(uint8_t on) {
  HAL_GPIO_WritePin(M1_EN_GPIO_Port, M1_EN_Pin,
                    on ? GPIO_PIN_RESET : GPIO_PIN_SET);
  HAL_GPIO_WritePin(M2_EN_GPIO_Port, M2_EN_Pin,
                    on ? GPIO_PIN_RESET : GPIO_PIN_SET);
}

// движение M1 (панорама) шагами до срабатывания концевика в направлении dir
uint32_t motor_pan_until_endstop(uint8_t dir) {
  GPIO_TypeDef* stop_port = (dir == PAN_DIR_LEFT) ? SWITCH_HOR_LEFT_GPIO_Port
                                                  : SWITCH_HOR_RIGHT_GPIO_Port;
  uint16_t stop_pin =
      (dir == PAN_DIR_LEFT) ? SWITCH_HOR_LEFT_Pin : SWITCH_HOR_RIGHT_Pin;
  return motor_until_endstop(M1_DIR_GPIO_Port, M1_DIR_Pin, M1_STEP_GPIO_Port,
                             M1_STEP_Pin, stop_port, stop_pin, dir);
}

// движение M2 (тильт) шагами до срабатывания концевика в направлении dir
uint32_t motor_tilt_until_endstop(uint8_t dir) {
  GPIO_TypeDef* stop_port = (dir == TILT_DIR_FRONT)
                                ? SWITCH_VERT_FRONT_GPIO_Port
                                : SWITCH_VERT_REAR_GPIO_Port;
  uint16_t stop_pin =
      (dir == TILT_DIR_FRONT) ? SWITCH_VERT_FRONT_Pin : SWITCH_VERT_REAR_Pin;
  return motor_until_endstop(M2_DIR_GPIO_Port, M2_DIR_Pin, M2_STEP_GPIO_Port,
                             M2_STEP_Pin, stop_port, stop_pin, dir);
}

// прошагать ровно steps шагов M1 (панорама) в направлении dir
void motor_pan_steps(uint32_t steps, uint8_t dir) {
  motor_steps(M1_DIR_GPIO_Port, M1_DIR_Pin, M1_STEP_GPIO_Port, M1_STEP_Pin,
              steps, dir);
}

// прошагать ровно steps шагов M2 (тильт) в направлении dir
void motor_tilt_steps(uint32_t steps, uint8_t dir) {
  motor_steps(M2_DIR_GPIO_Port, M2_DIR_Pin, M2_STEP_GPIO_Port, M2_STEP_Pin,
              steps, dir);
}

void motor_pid_init() {
  pid_init(&pid_pan, pan_kp, pan_ki, pan_kd, PID_DT_DEFAULT);
  pid_init(&pid_tilt, tilt_kp, tilt_ki, tilt_kd, PID_DT_DEFAULT);

  // Runtime-настройки — из констант (при повторном вызове сбрасываются)
  MotorPidParams d = {
      .pan_kp = PAN_PID_KP_DEFAULT,
      .pan_ki = PAN_PID_KI_DEFAULT,
      .pan_kd = PAN_PID_KD_DEFAULT,
      .pan_smooth = PAN_PID_SPEED_SMOOTH,
      .pan_rate = PAN_PID_OUTPUT_RATE,
      .pan_corr_max = PAN_PID_CORRECTION_MAX_FRACTION,
      .pan_speed_max = PAN_PID_SPEED_MAX_DEG_PER_S,
      .tilt_kp = TILT_PID_KP_DEFAULT,
      .tilt_ki = TILT_PID_KI_DEFAULT,
      .tilt_kd = TILT_PID_KD_DEFAULT,
      .tilt_smooth = TILT_PID_SPEED_SMOOTH,
      .tilt_rate = TILT_PID_OUTPUT_RATE,
      .tilt_corr_max = TILT_PID_CORRECTION_MAX_FRACTION,
      .tilt_speed_max = TILT_PID_SPEED_MAX_DEG_PER_S,
  };
  motor_apply_pid_params(&d);
}
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

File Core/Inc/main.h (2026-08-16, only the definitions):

#define USART_TX_Pin GPIO_PIN_2
#define USART_TX_GPIO_Port GPIOA
#define USART_RX_Pin GPIO_PIN_3
#define USART_RX_GPIO_Port GPIOA
#define M2_EN_Pin GPIO_PIN_6
#define M2_EN_GPIO_Port GPIOA
#define M2_DIR_Pin GPIO_PIN_5
#define M2_DIR_GPIO_Port GPIOC
#define M2_STEP_Pin GPIO_PIN_0
#define M2_STEP_GPIO_Port GPIOB
#define SWITCH_HOR_LEFT_Pin GPIO_PIN_1
#define SWITCH_HOR_LEFT_GPIO_Port GPIOB
#define SWITCH_HOR_RIGHT_Pin GPIO_PIN_2
#define SWITCH_HOR_RIGHT_GPIO_Port GPIOB
#define FAN_Pin GPIO_PIN_12
#define FAN_GPIO_Port GPIOB
#define SWITCH_VERT_FRONT_Pin GPIO_PIN_14
#define SWITCH_VERT_FRONT_GPIO_Port GPIOB
#define SWITCH_VERT_REAR_Pin GPIO_PIN_15
#define SWITCH_VERT_REAR_GPIO_Port GPIOB
#define M1_STEP_Pin GPIO_PIN_9
#define M1_STEP_GPIO_Port GPIOA
#define M1_DIR_Pin GPIO_PIN_10
#define M1_DIR_GPIO_Port GPIOA
#define M1_EN_Pin GPIO_PIN_11
#define M1_EN_GPIO_Port GPIOA
#define TMS_Pin GPIO_PIN_13
#define TMS_GPIO_Port GPIOA
#define TCK_Pin GPIO_PIN_14
#define TCK_GPIO_Port GPIOA
#define SWO_Pin GPIO_PIN_3
#define SWO_GPIO_Port GPIOB
#define LD1_Pin                   LED2_PIN
#define LD1_GPIO_Port             LED2_GPIO_PORT
#define LD2_Pin                   LED2_PIN
#define LD2_GPIO_Port             LED2_GPIO_PORT
#define LD3_Pin                   LED2_PIN
#define LD3_GPIO_Port             LED2_GPIO_PORT
#define USER_Btn_Pin              USER_BUTTON_PIN
#define USER_Btn_GPIO_Port        USER_BUTTON_GPIO_PORT
#define USB_PowerSwitchOn_Pin     GPIO_PIN_5
#define USB_PowerSwitchOn_GPIO_Port GPIOB
#define USB_OverCurrent_Pin       GPIO_PIN_4
#define USB_OverCurrent_GPIO_Port GPIOB

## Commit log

2026-07-14 Создал проект proto_turret: STM32F446RE Nucleo с FreeRTOS (CMSIS-RTOS v2), USART2, LED2, кнопкой BSP
2026-07-15 DMA transport + micro-ROS + rebuild_and_flash script
2026-07-15 Переключён GPG ключ на ed25519
2026-07-15 Добавлен gitignore для артефактов micro-ROS и скрипт сборки библиотеки
2026-07-15 flash.sh: переключен на .hex, добавлены проверки openocd и elf
2026-07-16 Сборка micro-ROS: фикс флагов и guard на скачивание
    - toolchain.cmake: переключен с {RET_CFLAGS} на
    (флаги из строки 11 теперь реально попадают в сборку)
    - Makefile: добавлена цель print_cflags для отображения флагов
    - library_generation.sh: блок скачивания обёрнут в проверку
    [ -d firmware/mcu_ws/ros2 ] — при повторных запусках не качает
    - rebuild_micro_ros_lib.sh: --rm убран, добавлен --name micro_ros_builder
    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
2026-07-16 feat: готовый транспорт UART2 DMA + IDLE для micro-ROS
    - dma_transport.c: неблокирующая проверка DMA-буфера перед ожиданием IDLE
    - Включение UART_IT_IDLE в cubemx_transport_open для надёжного RX
    - Очистка IDLE флага при открытии, отключение при закрытии
    - Интервал переподключения сессии увеличен до 60с (config.h.in + colcon.meta)
    - Исправлен colcon.meta: -UCLIENT_PROFILE_STREAM_FRAMING -> -DUCLIENT_PROFILE
    - Добавлены agent_start_native.sh (хостовый) и agent_start_kilted.sh (Docker)
    - CubeMX: GPIO init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
    [main.c, proto_turret.ioc]
2026-07-17 Успешный запуск издателя
2026-07-17 fix: agent_start_native.sh - полный путь, POSIX-совместимость
2026-07-17 Создал директорию с stl файлами
    [magnet_template_helper-Body.stl, magnet_template_helper.FCStd]
2026-07-17 Создал 2 поток для обработки входящих команд
2026-07-17 feat: кастомный msg TurretCommand + extra_packages всегда импортируются
2026-07-17 refactor: Ros2Init вынесена в отдельную функцию + очередь Reader→Executor
2026-07-20 Подключил шаговый двигатель
2026-07-21 Запуск реальных моторов
    [bottom_rails-Body.stl, bottom_rails-corner_side.stl, bottom_rails.FCStd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]
2026-07-23 Работа над stl-файлами
    [box-bottom_plate.stl, box-great_wall.stl, box-supply_unit_holder.stl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]
2026-07-24 Работа над моделью
    [box-wall_1.stl, box.FCStd]
2026-07-27 Работа на stl-моделями
    [box-Inter_stick.stl, box-wall_2.stl, box-wall_3.stl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]
2026-08-01 Почти закончил проектирование турели
    [motor_pan_gasket-motor_gasket.stl, motor_pan_gasket.FCStd, turret-door.stl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]
2026-08-03 Установочные пластины для as5600
    [as5600_plate-as5600_plate.stl, as5600_plate.FCStd, turret-head_konceviki_arms.stl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]
2026-08-03 Save commit
    [as5600_plate-as5600_plate.stl, as5600_plate.FCStd, bottom_rails-Body.stl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]
2026-08-03 Добавил датчики i2c
2026-08-05 Добавлен функционал считывания температуры с датчика lm75
2026-08-05 Добавил проверку для удобства отладки
2026-08-06 Перепроверил подключение и выделил ф-цию для датчика температуры
2026-08-07 Вкл/выкл вентилятор
2026-08-11 Тестовый запуск моторов
2026-08-11 Публикация структуры для qt-ноды + тест энкодера
2026-08-14 Тестовый запуск моторов и публикация энкодеров
2026-08-15 Начать разделение на модули
2026-08-16 Разделение на модули: motor_control
2026-08-16 Разделение на модули: turret_tasks/sensors
2026-08-16 Разделение на модули: вынес инициализацию
2026-08-16 Разделение на модули: вынес транспортный уровень
2026-08-16 Восстановление работы i2c шины в случае ошибок
2026-08-16 Убрал лазер, замкнул его перемычкой, всегда работает
2026-08-17 Добавить action для калибровки турели
2026-08-17 Добавил калибровку + фильтр от помех из-за длинных проводов
2026-08-18 Рефакторинг. Замена всех констант на осмысленные значения
2026-08-18 Реализовал первое сырое управление турелью
2026-08-19 Добавить получение корректных углов с энкодеров в топиках
2026-08-19 Корректная передача углов через основной топик
2026-08-19 Добавлена PID-регуляция для моторов
2026-08-20 Подготовка к передаче параметров через ROS parameters
2026-08-20 Создание нового сервиса для runtime pid параметров
2026-08-21 Создал readme.md

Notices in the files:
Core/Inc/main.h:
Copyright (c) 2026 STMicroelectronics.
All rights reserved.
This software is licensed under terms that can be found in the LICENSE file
